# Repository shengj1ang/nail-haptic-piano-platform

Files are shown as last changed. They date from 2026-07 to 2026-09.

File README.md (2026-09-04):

# Nail-Mounted Haptic Cues for Piano Training and Tele-training

Code repository for the MSc project of the same name. It documents the
platform implementation, operation, validation tools, and analysis workflow.
The complete project report is included as
[`shengjiang_final_report.pdf`](shengjiang_final_report.pdf).

The platform is a multimodal piano-guidance rig: a MIDI keyboard with per-key
LED backlighting, ten nail-mounted vibrotactile actuators driven by a Teensy
4.1, an overhead camera for finger-use detection, and the experiment software
that runs and analyses the studies built on top of it.

Everything is reachable from one hub window:

```bash
cd main && python launcher.py
```

---

## Documentation index

**Every document lives in [`doc/`](doc/).** This README is the index and stays
short: each subject below is written up in exactly one place, and nothing here
repeats it.

### Start here

| Document | What it covers |
|---|---|
| **[doc/USER_MANUAL.md](doc/USER_MANUAL.md)** | **How to use the software.** A screenshot walkthrough of every launcher button, section by section: what each window is for, the steps you take in it, and what it writes. Start here if you want to *operate* the platform. |
| **[doc/PLATFORM.md](doc/PLATFORM.md)** | **How the software is built.** Directory layout, the calibration→detection pipeline, the study runner and the analysis windows, the data-maintenance tools, and the haptic configuration. Start here if you want to *change* it. |
| [doc/firmware.md](doc/firmware.md) | The Teensy 4.1 firmware: motors, LEDs, accelerometers, and the complete serial protocol. |
| [shengjiang_final_report.pdf](shengjiang_final_report.pdf) | The complete project report: research rationale, formal methods, results, discussion, and appendices. |

### The experiments

Four strands of experimental work, in the order they were built. Each has its
own protocol and write-up.

| Study | Launcher | Document |
|---|---|---|
| **Actuator validation** — resonance, intensity, motor→ACC delay, spectra, adhesives | Validation Experiments | [doc/validation-experiments.md](doc/validation-experiments.md), plus one document per experiment below |
| **Main User Study** — which cue modality teaches a key-and-finger mapping best | Main User Study, Data Analysis | method chapter of the report; stimulus algorithm in [doc/SEQUENCE_GENERATOR_ALGORITHM.md](doc/SEQUENCE_GENERATOR_ALGORITHM.md) |
| **Tele-training** — guidance delivered over a network | Tele-training | [doc/REMOTE_GUIDANCE.md](doc/REMOTE_GUIDANCE.md) |
| **Rhythm experiment** — what survives when the cue is withdrawn | Rhythm Experiment | [doc/RHYTHM_EXPERIMENT.md](doc/RHYTHM_EXPERIMENT.md) |

The validation experiments are experiments in the same sense as the others,
and they come first in the dependency order: they are why the cue amplitude
and frequency are the values they are rather than a guess.

| Validation experiment | Document |
|---|---|
| LRA resonance and intensity calibration (frequency + amplitude sweeps) | [doc/validation-lra-resonance.md](doc/validation-lra-resonance.md) |
| Actuator spectrogram (drive-frequency × amplitude intensity map) | [doc/validation-actuator-spectrogram.md](doc/validation-actuator-spectrogram.md) |
| Motor → accelerometer delay (LRA/ERM command-to-vibration latency) | [doc/validation-motor-acc-delay.md](doc/validation-motor-acc-delay.md) |
| Adhesion vibration comparison (three mounting adhesives, LRA) | [doc/validation-adhesion-comparison.md](doc/validation-adhesion-comparison.md) |

### Algorithms

| Document | What it covers |
|---|---|
| [doc/SEQUENCE_GENERATOR_ALGORITHM.md](doc/SEQUENCE_GENERATOR_ALGORITHM.md) | The Main User Study's stimulus generator: matched bimanual sequence families per difficulty level (α/β/γ), constraint-driven, seeded, with automatic difficulty validation. |
| [doc/melody-generator.md](doc/melody-generator.md) | The rhythm experiment's melody generator: motif-and-phrase construction, melodic rules in scale steps, static fingering, whole-beat rhythm, and the scoring that selects a candidate. |

### Deployment and reference

| Document | What it covers |
|---|---|
| [doc/server.md](doc/server.md) | The tele-training relay server as an operator guide: accounts and rooms, HTTP↔HTTPS, JWT keys vs TLS certificates, deploying `main/server/` on its own, and the full REST + WebSocket reference. |
| [doc/runtime-bin.md](doc/runtime-bin.md) | The drop-in folder for ffmpeg / 7z, which the data-maintenance tools search before `PATH`. |
| [doc/archived.md](doc/archived.md) | Superseded prototypes and two completed one-off studies, kept for provenance. |
| [doc/legacy-accelerometer-reader.md](doc/legacy-accelerometer-reader.md) | Legacy standalone LIS3DH reader, pre-dating the unified firmware. Reference only. |

---

## Repository structure

```
./
├── doc/                  every document in this repository, plus doc/image/
│                         for the screenshots the user manual uses
├── main/                 the Python platform - launcher hub, calibration wizards,
│   │                     quiz and study tools, analysis, all four studies
│   ├── app/                     UI package: camera + MIDI finger-detection pipeline, GUIs
│   ├── common/                  shared low-level serial / motor / LED modules
│   ├── remote_guidance/         tele-training clients
│   ├── server/                  the relay server - imports nothing from the platform
│   ├── melody_generator/        rhythm-experiment stimulus generator (stdlib only)
│   ├── rhythm_study/            rhythm-experiment sessions and analysis
│   ├── validation_experiments/  hardware validation experiments
│   ├── data/                    calibration profiles, stimuli, and every study's data
│   └── test-script/             the test suite, plus older non-UI hardware scripts
├── teensy_driver/        Teensy 4.1 firmware: motors (async PWM), WS2812 LEDs, LIS3DH
├── 3d_model/             SolidWorks models and STLs for the actuator mounts and case
└── archived/             superseded prototypes and completed one-off studies
```

---

## Getting started

**Platform support.** The platform is tested on **macOS** and **Windows**.
Both run the same code — the differences are confined to how the rig is named
(serial ports and MIDI ports enumerate differently) and to where the optional
ffmpeg / 7z binaries are found, and both are handled in the code rather than
left to the operator.

### Windows — the bundled package

Download the archive from
[Releases](https://github.com/shengj1ang/nail-haptic-piano-platform/releases),
unpack it anywhere, and **double-click `main\launcher.bat`**. The launcher
window comes up; there is nothing to install.

The bundle carries its own Python 3.11 interpreter under
`main\runtime\Python311\`, and `launcher.bat` puts that interpreter and
`main\runtime\bin\` on the PATH **for that window only** — nothing is
written to the system PATH or to the registry, and a Python you already have
installed is left alone.

### macOS, Linux, or Windows from source

Python 3.11+ and the pinned dependency set:

```bash
pip install -r main/requirements.txt
cd main && python launcher.py
```

That requirements file also carries the tele-training dependencies;
`main/server/requirements.txt` lists the relay's alone, for deploying that
folder by itself.

**Hardware.** A Teensy 4.1 running the `haptic-piano` firmware (verify with the
`E` command — see [doc/firmware.md](doc/firmware.md)), a MIDI keyboard, two
WS2812 LED strips, ten vibrotactile actuators, and a camera positioned above
the keyboard.

**First run.** Work through the launcher's Initial Setup section in order —
camera selection, keyboard calibration, MIDI mapping — before anything else.
Every later tool reads the calibration profile those wizards produce.
[doc/USER_MANUAL.md](doc/USER_MANUAL.md) walks through each window with a
screenshot; [doc/PLATFORM.md](doc/PLATFORM.md) explains what sits behind them.

---

## Notes for reviewers

- **This repository is the implementation record.** It documents what the
  software does, how it is built, and how to operate it. The
  [project report](shengjiang_final_report.pdf) provides the full research
  rationale and formal study methods.
  Where a design decision is constrained by the study methodology, the code
  comments identify the corresponding report section.
- **Each study's data stays in its own folder** under `main/data/`, and the
  studies are isolated from one another structurally rather than by
  convention — the constraints are stated in each study's document and are
  enforced by tests.
- **The test suite** is `main/test-script/`:

  ```bash
  cd main && QT_QPA_PLATFORM=offscreen python -m pytest test-script/ -q --ignore=test-script/test_led_array.py
  ```

  `test_led_array.py` is excluded because it prompts for a serial port on
  stdin; it is a hardware tool, not an automated test.
- **The manual's screenshots are regenerated, not re-photographed.**
  `main/test-script/capture_manual_screenshots.py` renders every window
  offscreen against a disposable copy of the project, with the camera, serial
  ports and MIDI stubbed, and writes `doc/image/`.

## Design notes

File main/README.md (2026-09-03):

# The platform

The Python side of the project: camera + MIDI finger-use detection, the
per-key LED backlight, the vibrotactile cue path, and the tools that run and
analyse every study built on them. The repository front door and its
documentation map are one level up, in [`../README.md`](../README.md).

Everything is reachable from one hub window, which groups the tools into the
numbered sections used throughout this file:

```bash
python launcher.py
```

Every tool also runs standalone from its own entry-point script.

## Where to read what

This file documents the platform and the tools that have no document of their
own. Anything with a dedicated write-up is **linked, not repeated** — if a
subject appears below in more than a paragraph or two, this is the only place
it is written up.

| Subject | Document |
|---|---|
| Repository front door, install, structure | [`../README.md`](../README.md) |
| Firmware and the serial protocol | [`../teensy_driver/README.md`](../teensy_driver/README.md) |
| **Main User Study** stimulus algorithm | [`SEQUENCE_GENERATOR_ALGORITHM.md`](SEQUENCE_GENERATOR_ALGORITHM.md) |
| **Tele-training** (section 8) | [`REMOTE_GUIDANCE.md`](REMOTE_GUIDANCE.md), and [`server/README.md`](server/README.md) for the relay |
| **Validation experiments** (section 10) | [`validation_experiments/README.md`](validation_experiments/README.md), plus one README per experiment |
| **Rhythm experiment** (section 11) | [`RHYTHM_EXPERIMENT.md`](RHYTHM_EXPERIMENT.md), and [`melody_generator/README.md`](melody_generator/README.md) for the generator |
| Study protocols and rationale | [`../shengjiang_final_report.pdf`](../shengjiang_final_report.pdf) |

What is written up **here** and nowhere else: the directory layout, the
FingerAccuracy pipeline and calibration profiles (sections 1–3), the Main
User Study runner and the analysis windows (sections 6–7), the quiz data
maintenance tools (section 9), the haptic actuator configuration, and the
LED/audio helper modules.

## Layout

```
app/                            UI package: camera + MIDI finger-accuracy detection, quiz, generator
launcher.py                     entry point - hub window for every tool below, grouped into the same
                                 numbered sections used throughout this README (1 Initial Setup ...
                                 12 Demo & About). Section 8 Tele-training is the one
                                 section whose buttons start SEPARATE processes rather than a
                                 sub-window, because a student, a teacher and a relay have to run at
                                 the same time - see "Tele-training" below.
                                 Section 9 Tools is data housekeeping, not part of running or
                                 analysing a session - see "Quiz data maintenance tools" below.
                                 Section 11 Rhythm Experiment is a separate study, deliberately
                                 isolated so it cannot affect any of the others - see "Rhythm
                                 experiment" below.
                                 Section 1 also holds two launcher-only settings windows: Visual
                                 Guidance Cue Selection (app/gui/cue_selection_window.py), which
                                 persists the quiz cue style (dot/hand) to config.json, and Haptic
                                 Actuator Defaults (app/gui/haptic_config_window.py), which persists
                                 the actuator in use and each actuator's default frequency/amp to
                                 config.json's "haptic" block (see "Haptic actuator configuration")

setup_camera_wizard.py          entry point - camera selection/orientation (section 1: initial setup)
setup_keyboard_wizard.py        entry point - app/ calibration wizard (section 1: initial setup)
setup_midi_mapping_wizard.py    entry point - app/ MIDI mapping wizard (section 1: initial setup)

test_keyboard_preview.py        entry point - app/ profile preview/sanity-check (section 2: feature testing)
test_finger_accuracy.py         entry point - live finger/key detector (section 2: feature testing, see app/)
test_virtual_piano_led.py       manual-test UI (PySide6): on-screen piano that lights the physical LED
                                 strips (section 2: feature testing)
test_haptic_vibrator.py         manual-test UI: per-finger vibration motor check (section 2: feature testing)
app/gui/accelerometer_window.py manual-test UI (launcher-only): live X/Y/Z plot of one LIS3DH from the
                                 rig's ACC stream, sensor id selectable + persisted to config.json
                                 (accelerometer.sensor_id) (section 2: feature testing)

experiment_sequence_wizard.py   entry point - generates the controlled bimanual stimulus sequences for
                                 the main user study (30-event, difficulty alpha/beta/gamma, seeded, with
                                 built-in difficulty validation) and saves them under data/sequence/ -
                                 see SEQUENCE_GENERATOR_ALGORITHM.md (section 3: experiment sequence design)

music_recording_wizard.py       entry point - records a song (video+MIDI) and saves a fingering-annotated
                                 score under data/music/<song>/ (section 4: recording & playback)
music_playback.py               manual-test UI (PySide6): replays a saved song on an on-screen 88-key
                                 piano + finger dots (section 4: recording & playback, see app/music_recording.py)

student_quiz.py                 entry point - cue-response quiz with VISUAL finger cue (section 5: practice & assessment)
student_quiz_haptic.py          entry point - same quiz with HAPTIC finger cue (section 5: practice & assessment)

student_remote_guidance.py      entry point - Student Client: receives a remote teacher's key/finger
                                 guidance and cues it locally (section 8: tele-training)
teacher_remote_guidance.py      entry point - Teacher Client: turns what the teacher plays into
                                 guidance, and uploads/triggers pre-recorded sequences (section 8)
remote_latency_benchmark.py     entry point - relayed-path latency benchmark, CLI or --gui (section 8)
remote_guidance/                the tele-training client package (config, protocol, timing, network
                                 client, composite cue, student/teacher apps, benchmark) - see
                                 "Tele-training" below
server/                         the relay server: FastAPI REST + WebSocket, SQLite, JWT auth. Copyable
                                 on its own to a remote host; imports nothing from this platform.
                                 Full operator documentation in server/README.md
REMOTE_GUIDANCE.md              design + handover notes for the whole tele-training module: file map,
                                 the invariants that must not be broken (reaction-time origin, clock
                                 rules, what the server may not do), traps, and the list of known gaps.
                                 START HERE before changing anything under remote_guidance/ or server/
RHYTHM_EXPERIMENT.md            the rhythm experiment written up as Introduction / Method / Results /
                                 Discussion: the melody generation algorithm, the 19-trial
                                 cue-withdrawal design, the measures and the analysis plan.
                                 START HERE before changing anything under rhythm_study/
quiz_analysis.py                entry point - batch offline analysis of saved quiz sessions: outcome
                                 metrics table, LED sync alignment, per-event review/correction,
                                 carry-over review, participant CSV export (section 7: data analysis)
tool_compress_review_videos.py  entry point (console) - scans data/quiz/*/review.mp4 and converts only
                                 non-H.264 review copies with ffmpeg; never enters raw/. A thin
                                 frontend over app/review_compress.py, which the launcher's
                                 "Review Video Compression" window (section 9) also drives
tool_backup_quiz_to_zip.py      entry point (console) - participant backup: creates one tested
                                 data/quiz-zip/Pxx.zip for each complete P01-P20 participant.
                                 A thin frontend over app/quiz_backup.py, which the launcher's
                                 "Participant ZIP Backup" window (section 9) also drives

config.json                     app/ settings (auto-created): camera/MIDI, active_keyboard_profile,
                                 visual_cue_style, haptic (actuator in use + per-actuator default
                                 frequency/amp - see "Haptic actuator configuration"), and
                                 remote_guidance (the tele-training block: relay URL plus the
                                 student's and teacher's own camera/MIDI/profile/serial ports - it
                                 never redefines the shared camera/midi/active_keyboard_profile
                                 above; see "Tele-training")
data/keyboard-profile/<profile>/   app/ calibration profiles (see "app/" below)
data/music/<song>/               saved teacher recordings (see app/music_recording.py)
data/sequence/<name>/            generated stimulus sequences (same meta.json/fingering.json layout as
                                 data/music/, see app/sequence_generator.py)
data/sequence_validation/<batch>/   difficulty-validation output for a generated sequence batch
                                 (app/stimulus_validation.py, viewable in the Sequence/Music Metrics window)
data/quiz/<attempt>/             saved quiz sessions (video+MIDI raw + analysis results; results.json
                                 carries per-event validity - "valid"/"invalid_carryover" - set during
                                 the manual carry-over review; raw/ also holds sync_align.json - the
                                 trial's confirmed LED sync anchor - and sync_detect.json, the audit
                                 trail of the anchor last used)
data/quiz-zip/Pxx.zip            optional participant-level backups created by
                                 tool_backup_quiz_to_zip.py; never used as live experiment input
data/validation_experiments/<experiment>/   timestamped CSV/PNG/raw_acc.npz/meta.json runs of the
                                 validation experiments (see validation_experiments/ below); the
                                 raw_acc.npz holds the run's full three-axis accelerometer samples,
                                 so both intensity metrics and every chart can be regenerated
                                 offline
data/remote_guidance/latency/<run>/   latency benchmark output: samples.csv, summary.json,
                                 latency.png (see "Tele-training")
data/MainUserStudy/<participant>/   TrialStructure.json - the participant's randomised 27-trial
                                 schedule + live progress (see app/pilot_study.py); the Formal
                                 Experiment Session (launcher section 6, no standalone script)
                                 updates and resumes from this file after a crash. Also the export
                                 target: <P>_trials.csv / <P>_events.csv and figures/ (300 dpi
                                 PNGs + per-analysis CSVs from Participant Analysis)
hand_landmarker.task            MediaPipe hand landmark model, used by app/
requirements.txt                Python deps for app/ (conda env "fingercam")

profile_led_mapper.py           reusable, GUI-free: profile + MIDI note -> LED positions
note_led_map.py                 this LED rig's fixed wiring (position -> LED pixels), used by profile_led_mapper.py
note_audio.py                   reusable, GUI-free: MIDI note -> audio tone playback (no profile needed)

common/                         shared low-level modules (serial/motor/LED), used by both
                                 test_virtual_piano_led.py and test-script/
validation_experiments/         small hardware-validation experiments, separate from the main study
                                 (section 10: validation experiments) - one subfolder per experiment
                                 plus three shared modules: rig.py (serial helpers + the ACC sample
                                 collector), acceleration_metrics.py (the two vibration-intensity
                                 metrics, the counts -> m/s^2 conversion and the raw three-axis
                                 sample store) and report.py (the console-style text statistics each
                                 experiment can rebuild from a saved run, printed by the GUI when a
                                 run is loaded). GUI wrappers in
                                 app/gui/validation_experiment_window.py. Currently:
                                 lra_resonance_intensity_calibration/ (frequency + amplitude sweeps),
                                 actuator_spectrogram/ (2-D drive-frequency x amp intensity map),
                                 motor_acc_delay_experiment/ (LRA/ERM command-to-vibration latency)
                                 and adhesion_vibration_comparison/ (relative vibration transfer of
                                 three mounting adhesives, LRA-only, with its own three-run
                                 comparison analysis),
                                 each with a full write-up in its README.md; validation_experiments/
                                 README.md documents the shared metric/raw-data layer. Runs are saved
                                 as timestamped CSV/PNG/raw_acc.npz/meta.json sets under
                                 data/validation_experiments/<experiment>/
melody_generator/               SEPARATE STUDY (launcher section 11): standalone generator of short,
                                 simple, fixed-fingering practice melodies for the rhythm experiment.
                                 Stdlib only, shares no code with app/sequence_generator.py, writes
                                 only data/rhythm_experiment/ - see RHYTHM_EXPERIMENT.md
rhythm_study/                   SEPARATE STUDY (launcher section 11): the run-time and analysis half -
                                 the 19-trial schedule, the session controller and trial runner, and
                                 the whole analysis stage. Writes data/RhythmStudy/ and the
                                 rhythm- prefixed folders under data/quiz/ - see RHYTHM_EXPERIMENT.md
test-script/                    older, non-UI motor/LED/latency/MIDI scripts + their output
read_data_from_accelerometer/   legacy standalone LIS3DH sketch + plotters (old bare "x,y,z" serial
                                 format, pre-unified-firmware) - reference only, see its README;
                                 the live tool for the current rig is Accelerometer Live View above
../archived/python-prototypes/  the former archive/ folder: early FingerAccuracy prototypes,
                                 one-off utilities, and old bug reports - reference only
runtime                         Python Environment in Windows, python 3.11.9, do not use or read or change this diretory when in development
runtime/bin/                    optional drop-in folder for ffmpeg / 7z executables (see
                                 "Where ffmpeg and 7z come from" below). Searched before PATH;
                                 the executables themselves are not committed
venv.bat                        Do not read/write this file
launcher.bat                    Do not read/write this file
```

---

## Quiz data maintenance tools (launcher section 9)

Two tools for looking after data that has already been collected. Neither
is part of running a session or analysing one, and neither reads anything
the experiment reads.

Each has two frontends over one implementation:

| | window (launcher section 9) | console | shared logic |
| --- | --- | --- | --- |
| review videos -> H.264 | Review Video Compression | `python3 tool_compress_review_videos.py` | `app/review_compress.py` |
| participant backups | Participant ZIP Backup | `python3 tool_backup_quiz_to_zip.py` | `app/quiz_backup.py` |

The window and the script do the same thing to the same files, because
neither decides anything: **Scan** is the script's first phase, and
**Convert** / **Create archives** is what answering `1` at its prompt
does. Everything below describes both. The windows add only what a
terminal cannot: a table of what was found, an overall and a per-file
progress bar, a running log, and a **Stop** button.

Paths are anchored to this `main/` directory, so the scripts no longer
have to be run from here (though they still can be), and the windows work
wherever the launcher was started from.

Both windows keep running when you open another launcher tool - a
conversion pass is minutes of work and should not be thrown away by a
button press - and both are closed by closing the launcher.

### Where ffmpeg and 7z come from

Neither program is a Python dependency, so `app/tool_binaries.py` looks
for them in two places, in this order:

1. **`main/runtime/bin/`** - drop `ffmpeg.exe` / `7z.exe` (or their
   macOS/Linux equivalents) in that folder and nothing has to be
   installed on the machine. `launcher.bat` prepends the folder to `PATH`
   for the window it starts, and `app/tool_binaries.py` prepends it
   in-process as well, so anything the tools start themselves finds the
   same copy. Both are temporary: nothing is written to the system `PATH`
   or the registry.
2. **`PATH`**, as installed system-wide.

The lookup uses `shutil.which`, so on Windows the name `7z` finds
`7z.exe` without the extension being spelled out. 7-Zip is accepted under
any of the names `7z`, `7zz` or `7za` - all three can write and test the
ZIP archives the backup tool asks for.

Each window shows which copy it is using, or a warning naming
`runtime/bin` if it found none, and has a **Re-check** button so a
program dropped in there is picked up without restarting the launcher.
The console tools print the same message and exit with status 2 rather
than starting work they cannot finish.

### Compress generated review videos to H.264

```bash
python3 tool_compress_review_videos.py
```

Scans every direct `data/quiz/<attempt>/review.mp4`, reports its codec,
and asks before making changes. Files already encoded as H.264 and
unreadable or unknown files are skipped. The path pattern cannot enter
`data/quiz/<attempt>/raw/`, so original `raw/performance.mp4` recordings
are outside the tool's scope.

For each non-H.264 review, the tool renames the source to
`tmp-review.mp4` and runs this exact conversion command in that attempt
directory:

```bash
ffmpeg -i tmp-review.mp4 review.mp4
```

No options are added to it - the MP4 defaults, including H.264 video, are
the point. (The window's per-file progress bar reads the frame counter
from the stderr ffmpeg writes anyway, so watching a conversion needs no
extra flag either.)

The temporary original is deleted only after the output is non-empty,
confirmed as H.264, fully decodable by ffmpeg, and has exactly the same
frame count as the source. If ffmpeg is absent, disappears, fails,
produces an empty file, produces a non-H.264 file, or changes the frame
count, the source is not deleted. The tool restores the original
`review.mp4` and preserves any failed output as `failed-review.mp4` (or
the next unused numbered name). An existing `tmp-review.mp4`, output
file, or symbolic link is never overwritten.

Pressing **Stop** (or Ctrl-C) mid-conversion is handled as one more way
for that file to fail: ffmpeg is terminated, the original is put back,
and the discarded output is left as `failed-review.mp4` for you to look
at and delete. Files not reached yet are simply not touched.

Because a conversion is only safe if the result can be proved equivalent,
each file costs three ffmpeg passes - decode the original, encode, decode
the result - which is why the window has a per-file bar as well as an
overall one, and why a full pass over a study's worth of reviews is an
hour-scale job.

### Back up complete participants as ZIP files

```bash
python3 tool_backup_quiz_to_zip.py
```

Previews every archive it is ready to create and asks for confirmation
before creating `data/quiz-zip/`. Only participant directories matching
P01 through P20 and trial T01 through T27 are eligible. A participant is
archived only after all 27 trial numbers are present, preventing an
incomplete `Pxx.zip` from being permanently skipped as an existing backup
on a later run. `TEST-*`, `remote-*`, other unexpected directory names,
symbolic links used in place of trial directories, and `.DS_Store` files
at every depth are excluded.

Each participant is written first as `data/quiz-zip/tmp-Pxx.zip` with
`7z a -tzip`, so the archive format is ZIP rather than 7z. The temporary
archive must pass `7z t` before it is renamed to `Pxx.zip`. Existing
`Pxx.zip` and temporary archives are never overwritten. A failed,
stopped or interrupted temporary archive is preserved for inspection -
and must be removed by hand before that participant can be retried - and
no source directory or source file is ever deleted or modified.

This tool used to refuse to run anywhere but macOS. It no longer does:
the work is one 7z invocation over relative paths, which is as true on
Windows as it is on macOS, and which 7z to use now comes from the lookup
described above rather than from an assumed Homebrew install.

The window's table is the preview, one row per participant, and its
State column is the reason that participant is or is not being archived
("ready", "incomplete" with the missing trials named, "archive exists",
"temporary archive exists") - which between sessions is usually the
question being asked.

### Tests

```bash
python3 test-script/test_maintenance_tools.py
```

Runs against a temporary `data/quiz` built for each test; the project's
own data is never read or written. The conversion and archiving tests
skip themselves if ffmpeg or 7z is not available.

---

## Rhythm experiment (launcher section 11)

A study of its own, separate from the Main User Study. That one asks which
cue modality teaches best; this one asks what survives when a cue is taken
away. One 15-note melody, played 19 times, with guidance withdrawn on a
schedule:

    Training x5 -> Probe 1 -> Training x5 -> Probe 2 -> Training x5 -> Probe 3 -> Final test

| phase | backlight | haptic | task | n |
|---|---|---|---|---|
| Training | on | on | cue/response | 15 |
| Probe | on | off | performance | 3 |
| Final test | off | off | performance | 1 |

Five buttons, in the order a session uses them: **Rhythm Melody Generator
(15-note)** and **Playback Rhythm Melody** make and audition the stimulus;
**Rhythm Trial Schedule** locks a participant to one melody and writes their
19-trial schedule; **Rhythm Experiment Session** runs it (two windows - the
session controller and the trial runner - and no participant-facing cue
screen, because this study has no visual guidance); **Rhythm Group Analysis**
is the whole analysis stage.

**It cannot disturb any earlier experiment.** That is structural, not a
convention: `melody_generator/` shares no code with `app/sequence_generator.py`
and has no third-party dependencies, `rhythm_study/` never imports
`app/pilot_study.py` or `app/sequence_generator.py` (a test parses the imports
to enforce it), nothing here writes `config.json`, a keyboard profile,
`data/sequence/`, `data/music/` or `data/MainUserStudy/`, and its melodies are
not registered with `app/song_library.py` so one can never appear in the song
pickers. The two studies meet only in the shared `data/quiz/` folder, where
the `rhythm-` prefix separates them.

### Where the rhythm-experiment documentation is

This section is orientation only. Nothing below is repeated here:

| Document | What it covers |
|---|---|
| **[RHYTHM_EXPERIMENT.md](RHYTHM_EXPERIMENT.md)** | The study, written up as Introduction / Method / Results / Discussion: the research question, where it sits among the platform's four experiments, the melody generation algorithm, the 19-trial design, why training and the probes are different *tasks* and what that means for the timing measures, every derived measure, and the analysis plan. |
| [melody_generator/README.md](melody_generator/README.md) | The generator as a tool: CLI, config, the four generation ideas in detail, the hand layouts, the full validation-code list, the scoring, the output file formats, and using it as a library. |

## app/ - FingerAccuracy pipeline

Camera + MIDI based detection of *which finger* pressed *which piano key*.

### Where this fits

This is the "which finger pressed this key" piece of a bigger piano
practice / learning experiment setup. Roughly, the full pipeline looks
like:

```
cue shown -> participant presses a key
  -> MIDI logs the key + a timestamp -> camera works out which finger -> analysis after the fact
```

`app/` only covers the camera part, but it's built so it can be called from
the rest of that pipeline either live during a session, or later from a
recording - see [Using it as a library](#using-it-as-a-library).

### How it works

There are three steps, and only the first two need doing once per
physical setup:

1. Calibrate: click on the camera image to mark each key's exact pixel
   range (a paint-bucket style fill, bounded by Canny edges). This gets
   saved as a *profile* - `data/keyboard-profile/<profile_name>/keyboard_template.json` plus
   `keyboard_key_map.png`, a pixel map where each pixel's value is the key
   id it belongs to plus one (0 for background).
2. Map MIDI notes to those keys: press the keys in order 1, 2, 3, ... and
   whatever MIDI note number each one actually sends gets recorded next to
   the template, as `midi_mapping.json`.
3. Live detection: MediaPipe finds fingertip pixel positions every frame.
   On each MIDI note-on, look up which key that note belongs to, then
   check which fingertip's pixel is inside that key's region (or closest
   to it, if none are) - that's the finger used.

Left hand thumb -> pinky = `L1`..`L5`, right hand thumb -> pinky =
`R1`..`R5`. Works fine with 0, 1, or 2 hands in frame - both hands showing
up isn't required.

A profile only stays valid as long as the camera and keyboard don't move
relative to each other. If they do, just re-run step 1.

### Setup

```bash
conda activate fingercam    # or: conda env create ...; pip install -r requirements.txt
```

Everything runs inside the `fingercam` conda environment (Python, OpenCV,
MediaPipe, mido, PySide6). `hand_landmarker.task` (MediaPipe's model file)
is bundled in this folder already.

### Pipeline scripts

Run these from inside `main/`.

| Script | Purpose |
|---|---|
| `setup_keyboard_wizard.py` | PyQt wizard - calibrate a new profile (click-based, no keyboard shortcuts). |
| `setup_midi_mapping_wizard.py` | PyQt wizard - press keys 1..N in order, records the MIDI note each sends. |
| `test_keyboard_preview.py` | Utility/demo - pick a profile from a dropdown and sanity-check it against the live camera, optionally showing MIDI note names instead of key numbers. |
| `test_finger_accuracy.py` | The live app - keyboard overlay + hand skeleton + real-time finger/key matching. |
| `test_virtual_piano_led.py` | Manual-test UI - on-screen piano that lights the physical LED strips (see below). |
| `music_recording_wizard.py` | PyQt wizard - records a song (video+MIDI), flashes the LEDs for sync, and saves a fingering-annotated score under `data/music/<song>/`. |
| `music_playback.py` | Manual-test UI - replays a saved song on an on-screen 88-key piano, lighting a dot for whichever finger played each note. |
| `experiment_sequence_wizard.py` | Stimulus generator for the main user study - matched families of 30-event bimanual sequences per difficulty level (α/β/γ), constraint-driven (D = C_m/C_s/C_c), seeded for reproducibility, with automatic difficulty validation. Algorithm: `SEQUENCE_GENERATOR_ALGORITHM.md`. Includes the read-only "Sequence/Music Metrics" viewer (`app/gui/sequence_metrics_window.py`). |
| `student_quiz.py` / `student_quiz_haptic.py` | Cue-response quiz over a saved song/sequence: LED key cue plus a visual (`student_quiz`) or nail-mounted haptic (`student_quiz_haptic`) finger cue; records the whole session (video+MIDI) under `data/quiz/<attempt>/` for offline scoring. **Preview keyboard profile** draws the active calibration profile over the live camera image before recording - see [Checking the camera against the profile](#checking-the-camera-against-the-profile). |
| `quiz_analysis.py` | Batch offline analysis of saved quiz sessions: a checkable multi-quiz table with the report's full per-trial outcome measures, LED-anchored video/MIDI sync alignment (auto + manual), per-trial detail / per-event review-and-correction windows (including the carry-over validity review), and one-click per-participant CSV export - see [Data analysis](#data-analysis-launcher-section-7). |
| launcher section 6 (no standalone scripts) | The main user study tools: **Participant Trial Schedule** (`app/gui/pilot_schedule_window.py`) builds and saves a participant's randomised 27-trial schedule; **Formal Experiment Session** (`app/gui/experiment_session_window.py`) runs it - see [Main user study](#main-user-study-launcher-section-6). |
| launcher section 7, Participant Analysis (no standalone script) | Cross-trial single-participant analysis (`app/gui/participant_analysis_window.py`): condition/difficulty/learning charts, speed-accuracy trade-off, event-level error breakdown, finger confusion matrices, per-finger profiles - with 300 dpi figure + tidy CSV export. |
| `test_haptic_vibrator.py` | Manual test - drive each finger's vibration motor individually. |
| `setup_camera_wizard.py` | Camera selection/orientation wizard. |
| `launcher.py` | Hub window - one button per script above, grouped by stage; only one tool is open at a time (they share the camera). |

```bash
python setup_keyboard_wizard.py
python setup_midi_mapping_wizard.py
python test_finger_accuracy.py
python music_recording_wizard.py
python music_playback.py
```

Each script's docstring has more detail; `config.json` (auto-created on
first run) holds the camera index/flip settings, Canny thresholds, the
MIDI port, and which profile is "active" (used by default when a script
doesn't ask you to pick one).

**These wizards configure the machine the experiment runs on.** They
write the top-level `camera`, `midi.port_name` and
`active_keyboard_profile`, and the calibration wizard saves over
`data/keyboard-profile/<name>/`. That is what they are for - and it means
they are the wrong tool for onboarding a tele-training partner, because
each of those keys is what the quiz and the Formal Experiment Session
read, and a recorded session's scoring is only reproducible while its
profile folder stays as it was. For a remote student or teacher, use
**Tele-training Setup Wizard** (section 8) instead: the same calibration
work, saved into its own new profile folder and touching no config key.

### Checking the camera against the profile

The finger judgement is only ever as good as the camera still seeing the
keyboard the way it was calibrated - nudge the tripod and every key id
shifts, silently, and the first sign of it is a trial's finger accuracy.

**Preview keyboard profile** answers that in one click. It draws the
active profile's colored key masks and key ids over the camera image and
opens the result in its own window; nothing is saved. It is on:

- **Quiz - Visual Guidance** and **Quiz - Haptic Guidance** (section 5),
- the main study's **Trial runner** (section 6), which inherits it,
- both remote clients' Settings dialogs (section 8), where it opens the
  camera for one snapshot because those windows hold no camera yet.

In the three quiz windows it annotates the frame already on screen rather
than opening a second capture, since those windows hold the camera for
their whole lifetime. It uses `active_keyboard_profile` - the same
profile that trial is about to be scored with, not a separate choice -
and it is disabled while a quiz is recording. If the camera resolution
and the profile's mask disagree, it says so instead of stretching the
mask, because a stretched mask makes a wrong calibration look aligned.

The shared implementation is `app/gui/profile_preview.py`.

**Two keyboards of the same model report the same MIDI port name.** Every
port picker here lists them as `SE25 MIDI1 #1` and `SE25 MIDI1 #2`,
numbered in the order this machine enumerates them; a name that is
reported only once keeps exactly the name the driver gives it, so a
single-keyboard setup and any older `config.json` are unaffected. The
numbering is not a device identity - it can change when something is
replugged. `python test-script/MIDI.py` listens on every port at once and
prints which label a key press arrived on, which is the quickest way to
tell two identical instruments apart; `python test-script/midi_probe.py
"SE25 MIDI1 #2"` does the same for one port. On macOS, renaming the
instruments in Audio MIDI Setup → MIDI Studio makes the raw names differ
and the suffixes disappear.

### Main user study (launcher section 6)

The formal experiment tools have no standalone entry scripts - open them
from `launcher.py`, section "6. Main User Study":

1. **Participant Trial Schedule** (`app/gui/pilot_schedule_window.py`) -
   enter the participant's metadata, lock them to one generated stimulus
   batch under `data/sequence/`, and generate + save the randomised
   27-trial schedule (3 conditions x 3 levels x 3 unique sequences per
   cell, seeded shuffle, 2-min rests after trials 9 and 18) to
   `data/MainUserStudy/<participant>/TrialStructure.json`.

2. **Formal Experiment Session** (`app/gui/experiment_session_window.py`) -
   opens three windows at once:

   - **Session controller** - load a saved participant and see every
     trial's live status. Each row has a tick box plus its own Start
     button; shortcut buttons select the remaining trials of one
     condition ("Select remaining Visual (B)" etc.). "Run selected trials
     in order" walks the ticked trials smallest-index-first, pausing for
     a manual Continue between trials (with the 2-min rest countdown
     after trials 9/18). Every status change is written straight back to
     `TrialStructure.json`, so a crashed session reloads with its exact
     progress and resumes from the first non-completed trial.
   - **Trial runner** (`app/gui/experiment_runner_window.py`) - the quiz
     window re-purposed for scheduled trials: connect the LED strip and
     pick the MIDI port/timbre/timeout here once, and use **Preview
     keyboard profile** to confirm the camera still matches the
     calibration before the first trial. Every trial records an
     ordinary quiz under `data/quiz/`, named
     `<participant>-T<index>-<condition><level>` (a rerun appends `-r2`,
     `-r3`, ... so no attempt's data is overwritten), which means the
     existing analysis tools (Quiz Analysis, review video) work on pilot
     trials unchanged. The per-trial analysis popup is suppressed
     mid-session; batch the analysis afterwards from launcher section 7.
   - **Participant-facing cue screen** (`app/gui/experiment_cue.py`) -
     created once per session, so it can be dragged/fullscreened onto the
     external display one time instead of reopening every trial.
     Condition B draws the visual finger cue on it; conditions A and C
     show only a status line, so no visual finger cue leaks into them.

   The three feedback conditions (`app/pilot_study.py`): **A** key-light
   only, **B** visual finger cue (dot/hand style from `config.json`'s
   `visual_cue_style`), **C** vibrotactile finger cue (per-finger motors,
   `app/haptic_cue.py`, rig connected lazily on the first C trial).

   Trials always run with `config.json`'s `active_keyboard_profile` (MIDI
   mapping + LED layout, same as every quiz); the `keyboard_profile`
   stored inside `TrialStructure.json` is *not* used at run time - it only
   records which profile limited the sequence generator's key range when
   the schedule was made.

### Data analysis (launcher section 7)

Every stored time in the codebase is an absolute Unix epoch timestamp
(`time.time()` floats - no ISO strings, no recorder-relative clocks;
`../archived/python-prototypes/migrate_to_epoch_timestamps.py` converted the pre-existing
data). The analysis workflow, all reachable from launcher section
"7. Data Analysis":

1. **Quiz Analysis** (`quiz_analysis.py` /
   `app/gui/quiz_analysis_window.py`) - the per-trial hub. Every saved
   quiz is a row in a checkable table (filter box + select
   shown/analyzed/not-analyzed shortcuts) with the report's full outcome
   measures as columns: Key Accuracy, the three finger-accuracy views
   (FA main = key∧finger over all events - the primary measure; FA |
   key ok; Note Accuracy | finger ok), stratified reaction times,
   timeouts/wrong-key counts, the carry-over review state, QC extra-press
   counts, unresolved/ambiguous detection rates, same-hand vs hand-switch
   splits, per-finger FA/TE (L1-L5, R1-R5), and FA under alternative
   thresholds θ ∈ {0.30..0.50}.

   - **Video sync**: mapping MIDI timestamps to video frames goes
     through `app/sync_led.py` - the trial's LED flash is auto-detected
     in the footage (box matched filter with the commanded pulse width +
     two self-checks) and saved to `raw/sync_align.json`; the per-row
     "Video Sync" button opens a 3-frame manual alignment window
     (`app/gui/video_sync_window.py`) for trials the detector can't
     handle. A saved (especially manual) alignment always wins over
     re-detection. Per-trial camera start-up error is real: −0.2 s to
     +0.55 s measured across the pilot data.
   - **Analyze selected (from video)** runs the MediaPipe pipeline +
     review-video render per checked quiz - behind a confirmation
     dialog, because it overwrites the detected-finger fields in
     `results.json` (manual finger corrections are lost; carry-over
     validity verdicts are kept). **Auto-align selected** (also behind a
     confirmation) persists fresh LED-flash detections as `sync_align.json`,
     skipping anything already aligned.
   - **Double-click a quiz** for the per-trial detail window
     (`app/gui/quiz_detail_window.py`): all 30 events with verdicts,
     borderline-probability highlighting, a finger confusion matrix and
     distribution stats. **Double-click an event** there to play back
     its keypress ±5 s and correct the detected finger
     (`app/gui/event_review_window.py`) - corrections change
     `actual_finger` only (softmax kept as the audit trail) and are
     flagged in a Manual column. Saving rewrites `results.json` and
     re-derives the headline numbers cached in `meta.json` in the same
     step (`app.quiz.save_quiz_summary`), so an edited quiz is never left
     quoting pre-correction figures and there is no follow-up pass to
     remember. Nothing reads that cache anyway - the table, the export
     and Group Analysis all recompute from the per-event data - it exists
     so a quiz folder is readable on its own.
   - **Carry-over review**: a matched response faster than 100 ms
     (`CARRYOVER_RT_THRESHOLD_S`) cannot be a reaction to its cue - pilot
     data shows these are the tail of the previous event's presses
     crossing the 0.4 s inter-event gap. Such events are flagged
     "review!" in the detail window's Validity column (counted as
     `suspected_carryover`), never auto-labelled anticipation.
     **Right-click the event row** to confirm one as `invalid_carryover`
     (or restore it): confirmed events are excluded from every statistic
     - RT and accuracy alike - and reported as `excluded_carryover`.
     Unmatched raw presses (near-simultaneous double-hits + inter-trial
     strays) are QC/debug info only (`qc_*` export columns, the detail
     window's QC line); they never enter the main outcome measures.
   - **Export participant data** writes `<P>_trials.csv` /
     `<P>_events.csv` (no wall-clock timestamps - RTs, verdicts and
     validity only) next to the participant's `TrialStructure.json`.
     These files are snapshots and Group Analysis reads them rather than
     `results.json`, so this is the one step to re-run after a round of
     finger corrections or carry-over verdicts.

2. **Participant Analysis** (`app/gui/participant_analysis_window.py`) -
   cross-trial, within-subject: nine tabs (overview, learning
   progression incl. the within-cell trial 1→3 trend, difficulty,
   speed-accuracy trade-off, event-level error breakdown + wrong-key
   distance, per-condition finger confusion with a paper view, per-finger
   profiles + RT boxplots, RT distributions, data-quality audit), each
   with an auto-generated caption. Computations live GUI-free in
   `app/participant_analysis.py` (pandas DataFrames, participant-agnostic
   - ready for the future multi-participant aggregation) over the rows
   from `app/participant_export.py`, with unit tests in
   `test-script/test_participant_analysis.py`. "Export figures + data"
   writes 300 dpi PNGs + tidy CSVs (`<P>_<slug>.png/.csv`) under
   `data/MainUserStudy/<P>/figures/`.

   All participant-level readouts are descriptive; group-level inference
   is a separate, later step.

### Profile folder layout

```
data/keyboard-profile/<profile_name>/
  keyboard_template.json   # key ids, kind (white/black), note (usually null)
  keyboard_key_map.png     # pixel map: value = key_id + 1, 0 = background
  midi_mapping.json        # key_id -> MIDI note number (+ note name), from step 2
```

`data/` also holds the experiment data alongside these calibration
profiles, each kind in its own subfolder (`music/`, `sequence/`,
`sequence_validation/`, `quiz/`, `MainUserStudy/` - see the layout at the
top of this file).

Multiple profiles can coexist (different desks, cameras, keyboards); every
tool has a dropdown or `active_keyboard_profile` in `config.json` to pick
between them.

### Using it as a library

Nothing here is locked to the PyQt UI - the GUIs in `app/gui/`
are thin wrappers around plain functions/classes in the top-level package.

```python
from app import (
    Config, Camera, HandTracker, MidiListener,
    KeyboardTemplate, MidiMapping, match_note_to_finger,
)

cfg = Config.load()
template = KeyboardTemplate.load(f"data/keyboard-profile/{cfg.active_keyboard_profile}/keyboard_template.json")
mapping = MidiMapping.load(f"data/keyboard-profile/{cfg.active_keyboard_profile}/midi_mapping.json")

tracker = HandTracker()
midi = MidiListener()          # picks the first available port if none given;
                               # pass a name from list_input_ports() to choose one

with Camera(cfg.camera) as cam:
    while True:
        frame = cam.read()
        hands = tracker.process(frame)          # {"Left": Hand(...), "Right": Hand(...)}

        for event in midi.pop_events():         # MidiEvent(time, note)
            match = match_note_to_finger(event.note, template, mapping, hands)
            if match:
                print(match.finger, "pressed key", match.key_id + 1, "note", event.note)
```

#### Record now, analyze later

`MidiListener` timestamps every event with an absolute epoch `time.time()`
(the project-wide convention - see [Data analysis](#data-analysis-launcher-section-7)),
so a session's MIDI can be logged and matched against a recorded video
afterward instead of processed live:

```python
from app import MidiListener, save_midi_log, analyze_recording

midi = MidiListener()
# ... run your experiment, e.g. cv2.VideoWriter recording the same camera ...
save_midi_log(midi.pop_events(), "session1_notes.json")

# Later, with no camera or MIDI device needed:
results = analyze_recording(
    video_path="session1.mp4",
    midi_log_path="session1_notes.json",
    keyboard_profile_name="desk_webcam",
    sync_path="session1_sync.json",   # SyncInfo - see below
)
for r in results:
    print(r)   # FingerMatch(note=..., key_id=..., finger=..., inside=...) or None
```

Epoch event times are mapped to video frames through `sync_path` - a saved
`app.music_recording.SyncInfo` (video/MIDI start times plus the sync LED
flash times), which `app/sync_led.py` anchors on the flash it detects in
the footage; this is exactly how the recording/quiz tools save their
`raw/sync.json`. Without `sync_path`, event times are assumed to already
be video-relative seconds (the legacy pre-epoch convention only).

`Camera` also accepts a video file path in place of a live camera index
(`CameraConfig.index` takes either) - useful for replaying a recording
through the same live-style code path instead of `analyze_recording`.

### app/ module layout

```
app/
  camera.py                    # Camera - cv2.VideoCapture wrapper (index or video file)
  config.py                    # Config / *Config dataclasses, JSON load/save
  hand_tracking.py             # HandTracker, Hand - MediaPipe wrapper, L1-L5/R1-R5 fingertips
  midi.py                      # MidiListener, MidiEvent, save/load_midi_log, and the port
                               #   layer every tool enumerates/opens through:
                               #   list_input_ports / resolve_input_port / MidiInputReader
                               #   (rtmidi by index - mido cannot address two identical keyboards)
                               #   (all event times are absolute epoch timestamps)
  finger_matching.py           # match_note_to_finger, FingerMatch - the core matching logic
  offline.py                   # analyze_recording - recorded video + MIDI log -> matches,
                               #   frame mapping via the LED sync anchor (app/sync_led.py)
  sync_led.py                  # video/MIDI sync anchoring: LED flash detection, sync_align.json
                               #   persistence (manual > auto > start-times fallback)
  profiles.py                  # list_profiles - discover data/keyboard-profile/<name>/ folders
  music_recording.py           # song save/load (meta.json/fingering.json), raw capture, sync marks
  song_library.py              # combined data/music/ + data/sequence/ listing for song pickers
  sequence_generator.py        # stimulus generation: D = (C_m,C_s,C_c) metrics, level constraints,
                               #   matched families, seeded RNG (see SEQUENCE_GENERATOR_ALGORITHM.md)
  stimulus_validation.py       # difficulty validation of the alpha/beta/gamma level pools
  pilot_study.py               # main user study: 27-trial randomised schedules (3 conditions x
                               #   3 levels x 3 sequences, final report § "Design and Procedure"), saved to
                               #   data/MainUserStudy/<participant>/TrialStructure.json with
                               #   per-trial status for crash-resume
  quiz.py                      # cue-response quiz logic shared by the visual/haptic quiz tools
                               #   and the pilot study's trial runner; summarize() computes the
                               #   report's per-trial outcome measures (three FA views, RT
                               #   stratification, per-finger stats, threshold sensitivity) and
                               #   excludes human-confirmed invalid_carryover events, reporting
                               #   suspected/excluded carry-over counts; count_extra_presses()
                               #   is the QC-only unmatched-press breakdown (double-hits vs
                               #   inter-trial strays)
  participant_export.py        # one participant's trials/events as unified rows (the adapter the
                               #   analysis + CSV export share); disk-first quiz-dir resolution
                               #   (highest -rN retake wins)
  participant_analysis.py      # GUI-free cross-trial computations (pandas, participant-agnostic):
                               #   speed-accuracy trade-off, event outcome classification, finger
                               #   confusion, wrong-key distance - unit-tested in test-script/
  haptic_cue.py                # per-finger vibration cue driver used by the haptic quiz and the
                               #   pilot study's condition C trials
  tool_binaries.py             # finds ffmpeg / 7z: runtime/bin first, then PATH (see "Quiz data
                               #   maintenance tools"); imports nothing from the rest of app/
  review_compress.py           # GUI-free: scan + convert data/quiz/*/review.mp4 to H.264, with the
                               #   rollback rules that make deleting the original safe. Driven by
                               #   tool_compress_review_videos.py and the section 9 window
  quiz_backup.py               # GUI-free: eligibility + one tested data/quiz-zip/Pxx.zip per
                               #   complete participant. Driven by tool_backup_quiz_to_zip.py and
                               #   the section 9 window
  keyboard/
    template.py                # KeyBox, KeyboardTemplate - the pixel-exact key map
    wizard.py                  # KeyFillWizard - paint-bucket key segmentation
    midi_mapping.py            # MidiMapping - key_id <-> MIDI note
    visualize.py                # color/label helpers for drawing a key_map
    detector.py                 # Canny edge detection used by the calibration wizard
  gui/                          # PyQt windows/pages for the scripts above (incl. the sequence
                                #   generator window, metrics viewer, validation dialog, cue window,
                                #   profile_preview.py - the shared "camera vs calibration" check
                                #   used by both quizzes, the trial runner and the remote clients;
                                #   the pilot-study windows: participant schedule, formal-session
                                #   controller, trial runner, participant-facing experiment cue
                                #   screen; and the analysis windows: quiz_analysis_window,
                                #   quiz_detail_window, event_review_window, video_sync_window,
                                #   participant_analysis_window; and the section 9 maintenance
                                #   windows: maintenance_window.py - the shared shell (worker
                                #   thread, progress bars, log, tool status) - with
                                #   review_compress_window and quiz_backup_window over it)
```

`../archived/python-prototypes/` holds earlier, now-superseded prototypes of this same detector
(`detect_finger_with_MIDI_keyboard_v2/v3/v4.py` plus their pickled models),
kept only for reference.

---

## profile_led_mapper.py + note_led_map.py - MIDI note -> LED, and test_virtual_piano_led.py - manual test UI

This LED rig is hardware-specific and isn't meant to generalize to other
keyboards, but the identifier it's keyed by is: `note_led_map.py` only knows
about *this strip's fixed wiring* (which pixel(s) light up for the Nth
white/black key, left to right - see `test-script/test_led_array.py`), and
its `NoteLEDMapper.light_key(note)` / `clear_key(note)` take a MIDI note
number directly, no separate key_id.

`profile_led_mapper.py` is the reusable, GUI-free glue that combines that
wiring with a calibration profile's actual `key_id -> note` mapping (from
`data/keyboard-profile/<profile>/`, produced by `setup_keyboard_wizard.py` +
`setup_midi_mapping_wizard.py`) to build a ready-to-use `NoteLEDMapper` -
`build_mapper(led, profile_name)` is the one-shot entry point. Import this
directly in any script that needs "MIDI note -> light the right LED"
without pulling in a GUI.

`test_virtual_piano_led.py` is a thin PySide6 wrapper around the above,
for manual testing: pick a profile, and an on-screen piano mirroring that
profile's calibrated keys appears. Press and hold a virtual key (or the
matching real MIDI key) and the corresponding LED(s) on the physical
Teensy WS2812 strips light up; release to turn them off.

```bash
python test_virtual_piano_led.py
```

If the keyboard's transpose/octave setting changes, only the profile needs
re-calibrating (`setup_midi_mapping_wizard.py`) - `note_led_map.py`'s wiring table
doesn't need to change.

---

## note_audio.py - MIDI note -> audio tone playback

Reusable, GUI-free playback of a continuous tone for whichever MIDI note(s)
are currently held down, meant to be imported by future teaching modules
the same way `profile_led_mapper.py` is - a note-keyed `play_key(note)` /
`stop_key(note)` pair, mirroring `NoteLEDMapper`'s `light_key`/`clear_key`.
No calibration profile needed here: frequency comes straight from the MIDI
note number via the standard equal-tempered formula (note 69 = A4 = 440Hz),
since pitch is physics, not a fact about specific hardware.

```python
from note_audio import NoteAudioPlayer

with NoteAudioPlayer() as player:
    player.play_key(60)   # starts a middle-C tone, fades in
    ...
    player.stop_key(60)   # fades it back out
```

Uses `sounddevice` (already a project dependency via `test-script/measure_latency*.py`)
to mix all currently-held notes into one output stream, with a short linear
fade on press/release to avoid clicks.

---

## common/ - shared serial/motor/LED modules

Low-level modules shared by `test_virtual_piano_led.py` above and the scripts in
`test-script/` below. Not a UI on its own.

| Module | Purpose |
|---|---|
| `serial_utils.py` | Cross-platform auto-detection and opening of the serial port (USB/Arduino/Teensy first, with manual fallback). |
| `controller.py` | `VibratorController` - high-level async interface to the multi-motor vibration firmware (connect, pulse, stop). |
| `led_controller.py` | `LEDArrayController` - high-level interface to the Teensy WS2812 LED firmware (set pixel, clear, brightness). |
| `haptic_config.py` | The project's single source of truth for haptic actuator defaults: loads/validates/saves `config.json`'s `haptic` block, and hands every tool the actuator in use and its default frequency/amp (see "Haptic actuator configuration"). |

---

## test-script/ - older motor/LED/latency/MIDI scripts

Non-UI scripts from earlier stages of the project - motor control demos,
latency measurement, and MIDI/LED debugging tools. All import their shared
logic from `common/`.

| Script | Purpose |
|---|---|
| `demo_send_motor_command_async.py` | Demonstrates asynchronous motor control - starts one motor, injects others while it's still running, to show non-blocking behavior. |
| `demo_keyboard_control.py` | Real-time keyboard control - maps keys A-`;` to motors 0-9, supports multiple simultaneous key presses. |
| `detect_live_motor.py` | Real-time microphone-based detection tool for tuning vibration-detection parameters (threshold, frequency band). |
| `measure_latency.py` | Single-motor latency measurement - triggers a motor, detects the acoustic onset, estimates end-to-end latency. |
| `measure_latency_multi_motor.py` | Multi-motor latency measurement - random motor selection, multiple runs, per-motor comparison, automatic plotting into `latency_results/`. |
| `test_led_array.py` | Manual LED test script - lights specific pixels on specific strips to sanity-check wiring/colors. |
| `midi_probe.py` | Ground-truth calibration probe - prints the MIDI note number for each physical key as you press it, left to right. Takes an optional port name, so it can also check one specific instrument out of several. |
| `MIDI.py` | Minimal listener that prints every incoming note with the port label it arrived on, listening on **every** input at once - the quickest way to tell two identically named keyboards apart. |
| `plot_acc_from_ACC_stream_autostart.py` | Live-plots `ACC,x,y,z` accelerometer lines streamed over serial, sending the start/stop stream commands automatically. |
| `test_participant_analysis.py` | Unit tests for `app/participant_analysis.py` (the GUI-free cross-trial computation layer). |
| `test_acceleration_metrics.py` | Unit tests for `validation_experiments/acceleration_metrics.py` (both vibration-intensity metrics, unit conversion, the raw-sample round trip) and for the metric switching / old-CSV compatibility of the accelerometer experiments. |
| `test_haptic_config.py` | Unit tests for `common/haptic_config.py` and everything that reads it: old/partial `config.json` compatibility, range validation, atomic non-destructive saving, the Initial Setup window, the validation windows' defaults and prose, "manual value wins over the config", historical-run rendering, and the haptic quiz cue. |
| `test_validation_reports.py` | Unit tests for the validation experiments' text statistics (`validation_experiments/report.py` + each experiment's `summary_report()`) and for the saved-run picker in the validation windows. |
| `test_remote_setup_wizard.py` | Unit tests for the Tele-training Setup Wizard: opening it performs no camera scan/open; scan results require an explicit selection; calibration has Initial Setup's five pages and crop/full-frame coordinate handling; MIDI mapping loads the Middle C reference image and displays the live camera with next/mapped/unmapped key overlays; and neither flow can write config or a non-Tele-training profile. Cameras/MIDI are faked. |
| `test_chord_cue.py` | Unit tests for cueing a chord (remote guidance only): the haptic bitmask, the dot view's multi-highlight, the hand view's photo cycling, the LED's single flush, and the two guarantees that scope it - scoring stays single-note, and the single-finger path the local quiz and the main user study use is untouched. |
| `test_profile_preview.py` | Unit tests for `app/gui/profile_preview.py` and the **Preview keyboard profile** button the quiz windows inherit: the mask is drawn without touching the caller's frame, a resolution mismatch is refused rather than resized, the frame already on screen is used instead of a second capture, and every failure is reported rather than raised. No camera or profile on disk is needed. |
| `test_midi_ports.py` | Unit tests for `app/midi.py`'s port identity: two identically named keyboards both stay visible and are opened by index, older bare port names still resolve, and `MidiListener`/`RawMidiRecorder` end up on the port that was asked for. rtmidi is faked, so no keyboard is needed. |
| `test_quiz_summary_cache.py` | Unit tests for the `meta.json` summary cache (`app.quiz.apply_summary` / `save_quiz_summary`): a corrected finger and a confirmed carry-over both leave the cached headline numbers equal to what the analysis table and the participant export recompute live, `results.json` is never touched, and the identity fields (`guidance_type`, `note_count`, `analyzed`) survive a re-cache. Quiz folders are temporary; no video, MIDI or MediaPipe pass is involved. |
| `test_music_recording.py` | Unit tests for the saved-song lead-in - the gap between "the recording started" and "the playing started", which is the one place an absolute `time.time()` stamp and an elapsed duration can be mixed up silently - and for the two Song Recording Wizards writing a `meta.json` whose `duration_s` is the length of the piece rather than of the capture. Songs go to a temporary directory; no camera, MIDI device or MediaPipe pass is involved. |

`latency_results/` holds the plots/summary generated by the latency scripts;
`video_demo/` holds recorded demo videos of the latency tests.

Three things to know before trusting a latency number from these: motor pins
0 and 1 can conflict with serial on some boards, the supply has to be able to
drive every motor under test at once, and microphone placement dominates the
measurement. They estimate the *acoustic* end-to-end path - serial, MCU,
motor spin-up, sound propagation and audio capture together. The
instrumented, repeatable version of this measurement is the motor→ACC delay
experiment in launcher section 10, which uses an accelerometer instead of a
microphone: see
[validation_experiments/motor_acc_delay_experiment/README.md](validation_experiments/motor_acc_delay_experiment/README.md).

## Tele-training (launcher section 8)

Guidance delivered over a network: a teacher plays, a relay forwards, and
the student's LED strip and finger actuators fire from what the teacher
did. The three run as **separate processes** — a teacher, a student and a
relay have to be up at the same time, on different machines and holding
different devices — which is why this is the one launcher section whose
buttons start processes rather than sub-windows.

Six entries: **Relay Server**, **Teacher Client**, **Student Client**,
**Tele-training Setup Wizard**, **Network Latency Benchmark** and
**Remote Latency Analysis**. There is deliberately no shared settings
window: each of the three programs owns its own settings, because one
window showing all three roles' devices meant everyone was mostly looking
at settings that were not theirs.

To try it on one machine:

```bash
python -m server --init          # once: create the SQLite database
```

then start *Relay Server*, *Teacher Client* and *Student Client* from
section 8, in that order. Both clients arrive pre-filled with
`http://127.0.0.1:18765` and their demo account, so it is: sign in →
create/join a room → **Get ready** → **Ready for guidance** → **Start
teaching**.

### Where the tele-training documentation is

This section is orientation only. The module has two documents of its
own, and nothing here is repeated in them:

| Document | What it covers |
|---|---|
| **[REMOTE_GUIDANCE.md](REMOTE_GUIDANCE.md)** | The whole module. § 1–7 are the architecture: the three processes, the file map, the invariants that must not be broken (reaction-time origin, clock rules, what the relay may not do), the data flow of one live cue, the UI structure and the config schema. § 8–11 are running it, traps found the hard way, and known gaps. **§ 12 is the user-facing reference** — the setup wizard for a new machine, the guidance modes, what is reused from the local platform, provisional vs final results, which clock each timing measure is taken on, and the latency benchmark. |
| [server/README.md](server/README.md) | The relay as an operator guide: accounts and rooms, HTTP↔HTTPS and ws↔wss, JWT keys vs TLS certificates, deploying `server/` on its own, SQLite backup, and the full REST + WebSocket reference. |

Read REMOTE_GUIDANCE.md before changing anything under `remote_guidance/`
or `server/`.

## Haptic actuator configuration

Which vibration actuator the rig drives — and how hard — is **one setting
for the whole project**, stored in `config.json` and edited in the
launcher's **1. Initial Setup → Haptic Actuator Defaults**. No script,
window or experiment carries its own copy of "224 Hz / amp 64".

### Schema

```json
"haptic": {
  "using": "lra",
  "lra": { "default_frequency": 224, "default_amp": 64 },
  "erm": { "default_frequency": 1000, "default_amp": 50 }
}
```

| Field | Meaning | Default |
|---|---|---|
| `haptic.using` | Which actuator the platform drives by default — `"lra"` or `"erm"` (case-insensitive on load, stored lower case). | `"lra"` |
| `haptic.lra.default_frequency` | LRA drive frequency in Hz. | `224` |
| `haptic.lra.default_amp` | LRA drive amp (firmware PWM duty byte). | `64` |
| `haptic.erm.default_frequency` | ERM PWM **carrier** frequency in Hz. | `1000` |
| `haptic.erm.default_amp` | ERM drive amp. | `50` |

**The two frequencies do not mean the same thing.** An LRA's frequency is
a real mechanical drive frequency: the actuator only vibrates properly at
(or very near) its resonance, which is why
`validation_experiments/lra_resonance_intensity_calibration/` exists to
measure it. An ERM's frequency is the **PWM carrier** that chops its
drive rail — it is *not* the rotor's mechanical vibration frequency,
which follows the motor's speed and therefore the amp. The carrier only
has to be fast enough that the chopped drive behaves like smooth DC; too
low and the rotor cannot overcome stiction and never starts at all.

### Valid ranges

Enforced in one place (`common/haptic_config.py`) and used unchanged by
the Initial Setup spin boxes, so a control can never offer a value the
config would reject.

| Setting | Range | Where it comes from |
|---|---|---|
| amp (both actuators) | 0–255 | The firmware's PWM duty byte: `handlePulse()` rejects anything outside 0–255 (`teensy_driver/motor_driver.cpp`). |
| LRA frequency | 50–1000 Hz | Firmware `FREQ_MIN` = 50 Hz; the upper bound is the project's own LRA band (the Haptic Motor Bench's high-precision slider), and the resonance sweep only covers 100–350 Hz. |
| ERM frequency | 50–20000 Hz | Firmware `FREQ_MIN`/`FREQ_MAX` — the `F` command silently drops anything outside them. The project drives ERMs at 1–5 kHz. |

A frequency that is legal but unusual for that actuator (an LRA far off
resonance, an ERM carrier below ~1 kHz) is still accepted — this is a
research rig — but the Initial Setup window says so in an advisory note.

### What changing it affects

* the haptic quiz cue (`app/haptic_cue.py`) — amp **and** the PWM
  frequency it tunes each finger port to on connect;
* Haptic Vibrator Test and Haptic Motor Bench (their opening
  frequency/amp and "restore defaults");
* **Test Buzz** in every validation window, and the frequency pushed to
  the port before the pulse;
* Motor → ACC Delay: the actuator it opens on, and its motor port, PWM
  frequency and drive amp;
* Actuator Spectrogram: the type it opens on and its motor port;
* LRA Amplitude Sweep: the PWM frequency the amps are measured at;
* Adhesion Vibration Comparison: the frequency **and** amp it drives —
  always read from `haptic.lra` (even when `using` is `erm`) and shown
  read-only, so all three adhesives get an identical drive;
* the descriptions, tooltips and status lines of section 10 — they quote
  the configured numbers, not literals;
* the Wiring Guide's pin table (which actuator is in use, on which port).

### Priority: config defaults vs. what you type

The config supplies **initial values**; the operator always wins.

* A window reads the config when it **opens** and fills its controls.
* Anything typed afterwards is used for that run — the config is **never**
  re-applied at Start.
* Sweeps are unaffected in principle: the LRA resonance sweep still
  covers its whole 100–350 Hz range (finding the resonance is its
  purpose), the amplitude sweep still steps its own amp values, and the
  spectrogram still drives the ranges shown in its controls.
* Saved runs are immutable: a run's `meta.json` records what was actually
  sent to the hardware, and re-rendering an old chart uses **that**
  meta's parameters, never today's config. Runs saved before a field
  existed fall back to fixed historical constants, not to the config.
* New runs additionally record a `haptic_config` block: the config
  snapshot at run time, plus whether the amp / frequency / motor port
  used was the configured default or a manual override.

### Editing it

Initial Setup → **Haptic Actuator Defaults**: a radio pair for the
actuator in use plus a frequency and amp box for each actuator. Every
change is written to `config.json` **as you type** — no Save button and
no restart. Windows opened afterwards read the new values; validation
windows already open refresh their descriptive text (their controls are
left as the user set them).

Saving is read-modify-write and atomic (temp file + `os.replace`), so
every other key in `config.json` is preserved byte for byte and an
interrupted write can never leave unparseable JSON behind.

### Old config files

* No `haptic` key at all → the built-in defaults above are used; nothing
  is written until something saves.
* Some fields missing → only the missing ones fall back; the present ones
  are kept exactly.
* A malformed or out-of-range value → clamped into range (or, if it is
  not a number at all, replaced by the built-in default), with the
  correction reported in the log and shown in the Initial Setup window.
  Nothing out of range is ever sent to the hardware, and no correction is
  silent.

### What is deliberately *not* in this config

* **Motor port.** Which port an actuator is wired to (LRA → 11, ERM → 10)
  is a fact about the board, not a preference. The mapping is centralised
  in `common/haptic_config.py` (`ACTUATOR_MOTOR_PORTS`) so every window
  and experiment agrees on it, it is displayed in the Wiring Guide and in
  the Initial Setup summary, and every experiment window still has its
  own motor-port control that overrides it.
* **The firmware's boot PWM frequency** (224 Hz,
  `motor_driver.cpp DEFAULT_PWM_FREQ`). Experiments restore it on the
  port when they finish, so it must keep matching the firmware even if
  the configured LRA default changes.

---

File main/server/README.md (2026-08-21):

# Remote Guidance relay server

Routes key/finger guidance between a teacher client and a student client,
stores what happened, and answers latency probes. It is the only part of
the tele-training module that is not on a desk with hardware attached.

**Nothing here touches hardware.** This package imports no camera, MIDI,
MediaPipe, LED or haptic module - all of that runs on a client machine,
because the point of the relay is to move small JSON events, not to hold
devices. It also never re-runs finger matching and never computes its own
accuracy: the numbers it stores are the ones the student's own scoring
(`app.finger_matching`, `app.quiz.summarize`) produced, so the system has
exactly one definition of "correct".

---

## 1. Run it locally

From `main/` (the folder that contains `server/`):

```bash
python -m server --init
```

That writes `server/server_config.json`, creates the SQLite database, and
generates the JWT signing key pair. Then:

```bash
python -m server
```

The relay listens on `http://127.0.0.1:18765` by default (the clients
default to the same address; changing one means changing
`remote_guidance.config.NetworkConfig.server_url` and
`LocalServerConfig.port` too - a test asserts the three agree). Check it:

```bash
curl http://127.0.0.1:18765/api/v1/health
```

Other forms:

```bash
python -m server --gui
```

```bash
python -m server --host 0.0.0.0 --port 18765
```

Interactive API docs (FastAPI's own OpenAPI page) are at `/docs`.

### GUI vs CLI

`--gui` opens a Qt window (the launcher calls it simply **Relay Server**)
showing the bind host, port, registration state, database path, the HTTP
and WebSocket URLs, TLS on/off and run state, plus Start/Stop, the rooms
and clients currently connected, and the live server log.

Everything on that page is read-only. The editable settings - bind host,
port, whether registration is open, and the two token lifetimes - are
behind one **Settings** button, which writes `server_config.json`. It is
refused while the server is running, because the child process read its
configuration when it started; stop it first. TLS certificates and the
JWT signing keys stay out of that form deliberately: they are files, set
up once with `server/tools/`, and a text box inviting them to be retyped
would mostly produce a relay that cannot sign a token.

The panel does **not** run the server inside itself. It launches
`python -m server` as a separate process through `QProcess`, so Stop can
actually end it (terminate, then kill if it ignores that) and the port is
reliably released. Room/client rows come from the child process's own log
lines, which this window owns - no extra unauthenticated status endpoint
is exposed just to fill a dashboard.

The main panel opens at a compact **440 × 360 px**, also its minimum
size. The complete dashboard is wrapped in a resizable scroll area,
so server details, every button, the rooms/client tree and the server log
remain available without the window occupying most of a laptop screen.
The tree and log keep their own scroll bars as well.

The CLI form is what a headless deployment uses; the GUI is a convenience
for running the whole stack on one desk.

---

## 2. Accounts, rooms, joining

```bash
# teacher account
curl -X POST http://127.0.0.1:18765/api/v1/auth/register \
  -H 'Content-Type: application/json' \
  -d '{"username":"teacher1","password":"choose-a-long-one","role":"teacher"}'
```

```bash
# student account
curl -X POST http://127.0.0.1:18765/api/v1/auth/register \
  -H 'Content-Type: application/json' \
  -d '{"username":"student1","password":"choose-a-long-one","role":"student"}'
```

The response carries an access token and a refresh token.

A **teacher** creates a room and gets back a short join code:

```bash
curl -X POST http://127.0.0.1:18765/api/v1/rooms \
  -H "Authorization: Bearer $ACCESS" -H 'Content-Type: application/json' \
  -d '{"name":"Tuesday lesson"}'
```

A **student** joins with that code:

```bash
curl -X POST http://127.0.0.1:18765/api/v1/rooms/join \
  -H "Authorization: Bearer $ACCESS" -H 'Content-Type: application/json' \
  -d '{"join_code":"K7M4PQ"}'
```

Both clients have a form for this, so the curl calls above are only
needed for scripting or first-time setup. That form asks for a **join
code and nothing else** - no room id is ever typed into a client - and
the teacher reopens an existing room through this same `/rooms/join`
endpoint, which returns a room to its own owner without adding a
membership row. Keep that behaviour: it is what lets one field serve
both roles.

### The demo accounts

For development on one machine the clients' sign-in form arrives
pre-filled with `demoteacher` / `demostudent`. They are ordinary
accounts - register them once, on this relay, exactly as above:

```bash
curl -X POST http://127.0.0.1:18765/api/v1/auth/register \
  -H 'Content-Type: application/json' \
  -d '{"username":"demoteacher","password":"<the demo password>","role":"teacher"}'
```

The password each client fills in is the constant `DEMO_ACCOUNTS` in
`remote_guidance/gui_common.py`; nothing on this side knows or special-
cases those names, and the relay treats them like any other account. For
a real deployment, register proper accounts, set
`"allow_registration": false`, and empty that mapping so no password is
pre-filled.

Set `"allow_registration": false` once the accounts exist. The very first
account on an empty database is always allowed through, so that setting
cannot lock an operator out of a fresh install.

### Who may do what

Every REST call and every WebSocket frame is checked against the caller's
role *and* their membership row for that room:

- a teacher can only drive rooms they own - not another teacher's;
- a student can never send a teacher-only control
  (`guidance.live`, `session.*`, `recording.start/pause/stop`,
  `latency.probe`); the frame is refused and not relayed;
- a non-member gets 403 on the room's REST endpoints and is disconnected
  from its WebSocket before being registered.

The first version routes one teacher plus one active student per room.
The `room_members` table is already keyed by `(room_id, user_id)` with a
per-row role, so adding more students later is a routing change, not a
schema migration.

---

## 3. Configuring the clients

The clients are configured from the *root* `config.json` of the platform
(`main/config.json`), under a `remote_guidance` block - not from this
folder. Each client edits its own half from its own **Settings** button
(the student client shows the student's camera/MIDI/profile, the teacher
client the teacher's - neither sees the other's, and the launcher has no
settings window for them). This relay's own settings - bind host, port,
registration, token lifetimes - are the **Settings** button on the
control panel here, which writes `server_config.json`. Or edit the client
block by hand:

Each client Settings dialog can also take a one-shot camera photograph
and display the selected keyboard profile's colored pixel mask over it in
a separate preview window. It uses the form's current, possibly unsaved
camera/profile values and saves neither the picture nor the form. A
resolution mismatch is reported rather than resized into a false-looking
alignment. It is the same check the platform's quiz windows offer as
**Preview keyboard profile** (`app/gui/profile_preview.py`), so "is this
camera still aligned with the calibration?" is answered the same way
wherever it is asked.

This Settings dialog is also the only MIDI port selector for its role.
The student and teacher Session pages read the saved port directly and
do not repeat a MIDI dropdown or Refresh button. The teacher keeps a
manual **Connect MIDI** action beside **Chord detection** on its single
live-control row. There is no student-guidance selector on that row:
`visual` / `haptic` / `both` is selected by the student client on its own
Session page.

Teacher and student usually run the same model of keyboard, which reports
the same port name twice. The picker lists those as `... #1` / `... #2`,
numbered in the order the machine enumerates them, and warns that the
numbering can change when a keyboard is replugged. Give the two roles
different ones - identical values silently point both clients at one
instrument. See [../REMOTE_GUIDANCE.md](../REMOTE_GUIDANCE.md) §9.8.

```json
"remote_guidance": {
  "network": {
    "server_url": "http://127.0.0.1:18765",
    "verify_tls": true
  },
  "student": {
    "camera": {"index": 0, "width": 1280, "height": 720, "fps": 30},
    "midi": {"port_name": "SE25 MIDI1 #1"},
    "keyboard_profile": "white-city-lab-20260717",
    "led": {"port": "/dev/tty.usbmodem1101"},
    "haptic": {"port": "/dev/tty.usbmodem2201"},
    "default_guidance_mode": "both"
  },
  "teacher": {
    "camera": {"index": 1},
    "midi": {"port_name": "SE25 MIDI1 #2"},
    "keyboard_profile": "teacher-desk-20260801"
  }
}
```

Student and teacher each have their **own** camera, MIDI port and
keyboard profile; neither touches the shared `camera`/`midi`/
`active_keyboard_profile` keys the ordinary (non-remote) tools use.

The student's LED strip and haptic rig are both serial devices. Blank
ports use auto-detection; `student.led.port` and `student.haptic.port`
remain config-only overrides for a machine where the two similar boards
are detected incorrectly. Setting both overrides to the same port is
rejected with a clear error.

**No credentials live in `config.json`.** Usernames, passwords, tokens
and TLS private keys are never written there.

---

## 4. HTTP/ws → HTTPS/wss

Development default is plain `http` + `ws` on localhost.

**Recommended for anything real:** leave the relay on plain HTTP bound to
localhost and put a reverse proxy in front that terminates TLS. Caddy
obtains and renews a real certificate on its own:

```
relay.example.ac.uk {
    reverse_proxy 127.0.0.1:18765
}
```

Nginx equivalent (the two `Upgrade` headers are what keeps the WebSocket
working through the proxy):

```nginx
server {
    listen 443 ssl;
    server_name relay.example.ac.uk;
    ssl_certificate     /etc/letsencrypt/live/relay.example.ac.uk/fullchain.pem;
    ssl_certificate_key /etc/letsencrypt/live/relay.example.ac.uk/privkey.pem;

    location / {
        proxy_pass http://127.0.0.1:18765;
        proxy_http_version 1.1;
        proxy_set_header Upgrade $http_upgrade;
        proxy_set_header Connection "upgrade";
        proxy_set_header Host $host;
        proxy_read_timeout 3600s;
    }
}
```

Clients then use `https://relay.example.ac.uk` as their server URL; the
WebSocket URL is derived from it automatically (`wss://`).

**Direct TLS**, if you do not want a proxy: generate a development
certificate

```bash
python -m server.tools.generate_dev_certificate --host 127.0.0.1
```

then set in `server_config.json`:

```json
"tls": {"enabled": true, "certfile": "secrets/dev_cert.pem", "keyfile": "secrets/dev_key.pem"}
```

A self-signed certificate makes clients refuse the connection until it is
trusted, which is why it is never enabled by default.

### JWT keys are not the TLS certificate

Two different key pairs, two different jobs, and they are not
interchangeable:

| | JWT signing keys | TLS certificate |
|---|---|---|
| Files | `secrets/jwt_private.pem`, `secrets/jwt_public.pem` | e.g. `secrets/dev_cert.pem`, `secrets/dev_key.pem` |
| Created by | `python -m server.tools.generate_keys` (or `--init`) | `python -m server.tools.generate_dev_certificate`, or a CA / Caddy / certbot |
| Proves | that a token was issued by this server and has not been altered | that the *host* you connected to is the one you meant |
| Seen by | nobody outside the server; only the public half verifies | every client, during the handshake |
| Rotating it | logs everyone out (all tokens become unverifiable) | needs a client reconnect, tokens are unaffected |

A deployment behind Caddy/Nginx has JWT keys here and its TLS material in
the proxy. That is normal - the relay still signs tokens either way.

### Tokens and sessions

Access tokens last 30 days and refresh tokens 180 days by default
(configurable). That is deliberately long so a lesson series does not get
interrupted by a re-login, which makes revocation the important part:

- `POST /auth/logout` blacklists the presented access and refresh tokens
  by their `jti`;
- `POST /auth/refresh` rotates - the refresh token you present is spent,
  so a stolen copy stops working as soon as the real client refreshes;
- a revoked `jti` is rejected even while its `exp` is still in the future.

Server logs never contain a password or a whole token.

---

## 5. Deploying this folder on its own

`server/` has no dependency on the rest of the repository. To move it:

```bash
scp -r server/ user@host:/opt/remote-guidance/
```

```bash
ssh user@host
cd /opt/remote-guidance
python3 -m venv .venv && . .venv/bin/activate
pip install -r server/requirements.txt
python -m server --init
python -m server --host 0.0.0.0 --port 18765
```

Run it from the directory that *contains* `server/`, so `python -m
server` resolves. Note that `secrets/` and `server_config.json` are
git-ignored, so a fresh copy generates its own - which also means tokens
issued by the old host will not verify on the new one.

As a systemd unit:

```ini
[Unit]
Description=Remote Guidance relay
After=network.target

[Service]
WorkingDirectory=/opt/remote-guidance
ExecStart=/opt/remote-guidance/.venv/bin/python -m server --host 127.0.0.1 --port 18765
Restart=on-failure
User=relay

[Install]
WantedBy=multi-user.target
```

Bind to `127.0.0.1` when a proxy terminates TLS in front; bind to
`0.0.0.0` only when the relay itself is the edge.

---

## 6. Backing up SQLite

The database is `data/remote_guidance.db` (plus `-wal`/`-shm` sidecars,
because it runs in WAL mode). **Do not copy those three files while the
server is running** - use SQLite's own online backup, which is consistent
without stopping anything:

```bash
sqlite3 data/remote_guidance.db ".backup 'backup/relay-$(date +%F).db'"
```

Or from Python:

```bash
python -c "import sqlite3,sys; s=sqlite3.connect(sys.argv[1]); d=sqlite3.connect(sys.argv[2]); s.backup(d); d.close(); s.close()" \
  data/remote_guidance.db backup/relay.db
```

Restoring is just putting the file back and starting the server; the
schema version is checked and migrated forward on start (`PRAGMA
user_version`), so an older backup upgrades in place.

No video is ever stored in the database. Recordings hold the note/finger
event list needed to drive cues; the media stays on the machine that
captured it, so a backup stays small.

---

## 7. REST API

All paths are prefixed `/api/v1`. Everything except `/health`,
`/auth/register`, `/auth/login` and `/auth/refresh` needs
`Authorization: Bearer <access token>`.

| Method | Path | Who | What |
|---|---|---|---|
| GET | `/health` | anyone | liveness, protocol/schema version, room and connection counts |
| POST | `/auth/register` | anyone (if enabled) | create an account, returns a token pair |
| POST | `/auth/login` | anyone | token pair |
| POST | `/auth/refresh` | refresh token | new pair; the presented refresh token is spent |
| POST | `/auth/logout` | any user | revoke the presented access/refresh tokens |
| GET | `/auth/me` | any user | the caller's account |
| POST | `/rooms` | teacher | create a room, returns its join code |
| POST | `/rooms/join` | any user | join by code |
| GET | `/rooms/{room_id}` | member | room details |
| POST | `/rooms/{room_id}/close` | owning teacher | close the room |
| GET | `/rooms/{room_id}/members` | member | members + who is online now |
| POST | `/rooms/{room_id}/recordings` | owning teacher | upload a fingering/MIDI sequence (metadata + events, no video) |
| GET | `/rooms/{room_id}/recordings` | member | list them |
| GET | `/recordings/{recording_id}` | member | full event list - the student downloads this **before** playback |
| POST | `/rooms/{room_id}/sessions` | owning teacher | open a guidance session; the teacher does not select the student's rendering mode |
| GET | `/sessions` | any user | list the caller's sessions, newest first, with event counts |
| GET | `/sessions/export` | any user | every guidance + performance event of many sessions in one reply |
| GET | `/sessions/{session_id}` | member | session state |
| GET | `/sessions/{session_id}/events` | member | stored guidance + performance events |
| GET | `/sessions/{session_id}/summary` | member | counts, plus the student's own reported summary |

`/sessions/{id}/summary` returns the student's result under
`student_reported_summary` with `summary_source: "student"`. The naming
is deliberate: the server did not compute it.

### Getting a study's timing data off a deployed server

Every other session route needs a session id you already have. During a
lesson the clients do have it, but after the fact the ids only exist in
whatever each client wrote locally - the Student Client records the
session id in its `data/quiz/<session name>/meta.json` as
`song_name: "remote:<session id>"` - and a folder that was never copied
off the student machine leaves the matching server rows unreachable
without a shell on the box. `/sessions` and `/sessions/export` exist for
that case and do nothing else.

    # what is there
    GET /api/v1/sessions?since=<unix seconds>&limit=200
    # pull it
    GET /api/v1/sessions/export?since=<unix seconds>&limit=100
    GET /api/v1/sessions/export?session_ids=<id>,<id>,<id>

`/sessions` returns each session plus `guidance_event_count` and
`performance_event_count`, so a session that recorded nothing can be
skipped without a second request, and `truncated: true` when more matched
than `limit` allowed through. Both accept `room_id`, `since` and `state`;
`limit` caps at 1000 for the listing and 500 for the export, and asking
for more explicit `session_ids` than `limit` is a 400 rather than a
silent trim.

Authorisation is the same membership rule as the single-session routes,
applied through the same helper: a session in a room the caller never
joined is never listed, naming that room outright is a 403, and an
explicit `session_ids` entry from another teacher's room is a 403 rather
than a silent omission. Neither endpoint can write anything.

The export returns stored payloads verbatim - in particular the per-cue
`timings` dictionary the Student Client sends with each performance row
(`teacher_send_wall_ns`, `server_receive_wall_ns`,
`student_receive_wall_ns`, then the student's own monotonic
`queue_enter` / `cue_dispatch_start` / `led_command_complete` /
`haptic_command_complete` / `visual_painted` / `cue_ready` marks). Read
`timing_kind: "software_dispatch_render"` before using any of it: those
are dispatch and render moments on the student's machine, not physical
LED or actuator onset, and the wall-clock marks come from three different
machines' clocks. Section 9's caveats apply unchanged - the monotonic
marks may be subtracted from each other, the wall-clock ones may not.

The current teacher sends `{"mode": "live"}` when opening a live
session. Its initial `guidance_mode` is the neutral value
`student_choice`, not a visual/haptic default. Once the student is ready,
its session-bound `recording.ready` frame reports `visual`, `haptic` or
`both`; the background writer stores that student-reported value on the
session. Older clients may still send a concrete value in the REST body,
but the student's later ready message remains authoritative.

The Teacher Client's Recorded guidance tab follows the same ownership
rule. After uploading the selected song's note/finger events, Trigger
creates a separate session with `mode: "recording"`, `recording_id` and
`playback_mode` (and no teacher guidance modality), then sends
`session.start` followed by `recording.start`. It no longer creates or
borrows a live session merely to enable recorded playback. A student
that has not yet entered Ready state retains the one-shot
`recording.start` envelope locally and consumes it immediately after it
becomes ready.

A recording upload never writes to either client's song library. It
inserts a new uuid-keyed recording and event rows in SQLite, so uploading
the same named source again creates another relay record instead of
overwriting the previous one. The student consumes the downloaded event
list in memory; its performed-session files are written separately by
the client under `data/quiz/<session name>/`.

---

## 8. WebSocket

One persistent connection per client:

```
/ws/v1/rooms/{room_id}
```

The **first frame must be an `auth` envelope** carrying the access token
in its payload. The token is not put in the URL query string, where it
would end up in proxy logs and browser history. Membership of the room in
the path is checked before the connection is registered, so an
unauthenticated socket never receives another room's traffic.

Every frame is one JSON envelope:

```json
{
  "v": 1,
  "type": "guidance.live",
  "message_id": "8f14e45f-ceea-467a-9f0a-8b1e4a1c53d1",
  "room_id": "…",
  "session_id": "…",
  "seq": 42,
  "sent_at_unix_ns": 1786000000000000000,
  "payload": {}
}
```

The relay adds its own block and never rewrites `sent_at_unix_ns`:

```json
"server": {
  "receive_wall_ns": 1786000000001234000,
  "send_wall_ns":    1786000000001250000,
  "sender_user_id": "…", "sender_username": "…", "sender_role": "teacher",
  "out_of_order": false
}
```

Message types:

| Type | Sender | Meaning |
|---|---|---|
| `auth` | client → server | first frame; token in payload |
| `presence` | server → room | who is connected now |
| `heartbeat` | client ↔ server | keep-alive, echoed with server stamps |
| `guidance.live` | teacher | one or more `actions` (note + finger + probabilities) with a `timeout_s` |
| `guidance.received` | student | arrived; sent *before* any cue is presented |
| `guidance.presented` | student | local cue is ready, with the student's own dispatch timings |
| `performance.response` | student | what was actually played; `stage` is `provisional` or `final` |
| `session.start` / `pause` / `resume` / `stop` | teacher | session control |
| `session.finished` | student | end of session + the student's own summary |
| `recording.ready` | student | ready for guidance; reports the student's selected modality and enabled output channels |
| `recording.start` / `pause` / `stop` | teacher | remote trigger for that sequence |
| `latency.probe` | teacher | benchmark probe |
| `latency.received` | student | immediate ack - this is what transport RTT ends on |
| `latency.presented` | student | after the local cue dispatch completed |
| `latency.ack` | server → sender | the relay accepted and forwarded the probe (isolates the teacher→server hop) |
| `error` | server → sender | refused frame; `code` says why, `fatal` says whether the socket survives |

Robustness rules the relay enforces:

- frames larger than 64 KiB are rejected before being parsed;
- a repeated `message_id` is **not** relayed twice - the sender gets an
  `error` with code `duplicate_message` instead, so a reconnecting client
  replaying its outbox cannot double-cue the student;
- a `seq` that goes backwards is flagged `out_of_order` in the server
  block but still delivered, because dropping a late cue silently would
  be worse than showing it late;
- `room_id` in a frame must match the socket's room;
- a client may reconnect and re-authenticate at any time; heartbeats
  detect a dead path in between.

---

## 9. Latency benchmark

Run from `main/`:

```bash
python remote_latency_benchmark.py --server http://127.0.0.1:18765 \
  --username teacher1 --student-username student1
```

This default run is self-contained: the benchmark authenticates both
existing accounts, creates a temporary room, joins and connects its own
simulated Student WebSocket, reads the room's membership back from the
relay so the run shows both accounts really were in one room, then closes
the room without deleting its database record. Only the relay and
benchmark processes need to be open.

No room ever has to be created or pasted in by hand. `--external-student`
creates the room here as well, prints its join code for a real Student
Client, and waits (`--wait-for-student`, default 180 s) until a `presence`
frame shows a student in the room before it starts probing. Use it only
when a real Student Client and its UI/LED/haptic dispatch are
intentionally part of the measurement. `--room-id <id>` is for the single
case where that Student Client has already joined a room of its own.

Defaults follow the report's benchmark: **1000 probes at 500 ms
intervals over one persistent WebSocket per endpoint**, with warm-up samples
recorded separately and excluded from the statistics.

`--interval-mode` chooses how the probes are spaced. The default `fixed`
period is easy to describe but samples the same phase of anything
periodic in the path on every probe; `uniform` jitters each wait by
`--interval-jitter` of the interval, and `poisson` draws it from an
exponential distribution (RFC 2330 § 11.1, truncated at 5x the mean).
`human` paces probes like a person being cued. It is fitted at run time
to every trial of whichever participants are in `data/quiz/` (at 14
participants: median 664 ms, log-sigma 0.441 over 11,335 trials, ~0.7 s),
and samples hierarchically - a participant, then that participant's own
lognormal - because pooling every trial inflates sigma. The fitted median
is also its default interval. Lognormal is checked against ex-Gaussian
and shifted lognormal rather than assumed, and a bootstrap interval is
reported with it; the CLI prints progress while it reads. Each run
records the population it used in `summary.json`. The first three modes
share one mean, so only the spacing pattern changes; `human` has its own
median and a mean above it. The pacing seed is recorded in
`summary.json` and can be replayed with `--interval-seed`. Results land in
`data/remote_guidance/latency/<run_id>/` as `samples.csv`,
`summary.json` and `latency.png`.

### What is measured

| Metric | Definition |
|---|---|
| **Transport RTT** | teacher's `perf_counter_ns` at probe send → same clock when `latency.received` arrives. **Primary metric.** |
| Teacher→server ack | probe send → the relay's `latency.ack`. Isolates which hop is slow. |
| Cue-presented RTT | external-Student mode only: probe send → `latency.presented`, including real Student local cue dispatch |
| Student dispatch duration | external-Student mode only: measured entirely on the real Student's monotonic clock |
| One-way estimate | see below |
| Loss | probes with no valid ack before the timeout, as a proportion of the run |

Reported for each: n, lost, loss rate, min, mean, standard deviation,
median, p95, p99, max.

### Why cross-machine timestamps are not one-way latency

`T_receive,B − T_send,A` is only a latency if A's and B's clocks agree.
Two independent computers do not: their wall clocks differ by an unknown
offset that is often larger than the delay being measured, so the
subtraction can even come out negative. The tool therefore:

- reports **RTT as the primary transport measure**, since both stamps
  come from one clock on one machine and no synchronisation is needed;
- reports a one-way figure **only** when both ends are NTP-synchronised
  and the estimated offset uncertainty is recorded alongside it;
- otherwise shows `RTT/2`, labelled explicitly as a *symmetry-based
  estimate* - which assumes the two directions are equally fast, and they
  often are not.

A lightweight four-timestamp offset estimator (many exchanges, lowest-RTT
samples preferred, uncertainty retained) is included so the assumption
can at least be quantified. It is **not** NTP and is not presented as a
substitute for it; `time.is` or `chronyc tracking` before a run remains
the sanity check.

Monotonic timestamps are never subtracted across machines. They are used
only on the machine that produced them, and travel as opaque values
otherwise.

### Software timing, not physical onset

Everything above is **software dispatch/render timing**: the moment a
command was written and flushed, or a frame was painted. It is not the
moment an LED emitted light or a motor started moving. Measuring physical
onset needs a photodiode on the key and an accelerometer on the actuator
sampled on one acquisition clock (the report's
`System Transmission Performance Benchmarking`); the schema keeps fields
free for that, and this tool does not claim it.

### Why student reaction time does not start at the teacher's send time

Student reaction time is always

```
reaction_time_ns = student_response_monotonic_ns - cue_ready_monotonic_ns
```

Both terms come from the student's own monotonic clock. `cue_ready` is
the moment the student's cue was actually ready - the maximum of the LED
command completing, the screen paint finishing, and the haptic serial
flush returning, over whichever channels that session enabled.

Starting the clock at `teacher_send`, `server_receive` or
`student_receive` would fold network delay, queueing and local dispatch
into a number describing a *person*, so a slow network would look like a
slow learner. Those transport figures are all recorded, separately, on
the same event - they are simply never part of the reaction time.

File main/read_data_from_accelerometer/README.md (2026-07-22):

# read_data_from_accelerometer - legacy LIS3DH reader

Early standalone accelerometer tooling, kept as reference. These files
predate the unified haptic-piano firmware (`teensy_driver/`): the
bundled sketch bit-bangs SPI to a single LIS3DH and prints bare
`x,y,z` lines, and the two Python scripts parse exactly that format.

| File | Purpose |
|---|---|
| `read_data_from_accelerometer.ino` | Old standalone Teensy sketch: software-SPI LIS3DH readout, prints `x,y,z` per sample. Superseded by `teensy_driver/accel_driver.cpp`. |
| `plot_lis3dh.py` | Live matplotlib X/Y/Z plot of those `x,y,z` lines. |
| `read_serial_live.py` | Raw serial line printer (debug). |

**For the current rig, use the launcher instead**: section
"2. Feature Testing" → **Accelerometer Live View**
(`app/gui/accelerometer_window.py`). It speaks the current firmware
protocol (`A START <ms>` / `ACC,<id>,x,y,z`, firmware >= v2.5.0),
lets you pick which sensor id to follow (persisted to `config.json`
as `accelerometer.sensor_id`, also the default sensor in the
validation sweep windows), and runs the serial I/O off the GUI thread.
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

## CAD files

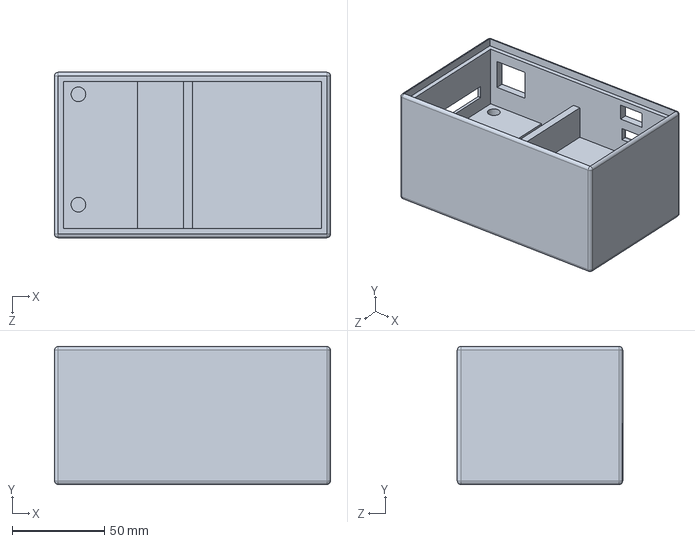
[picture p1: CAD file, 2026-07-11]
3d_model/main.SLDPRT
150.0 x 75.0 x 90.0 mm

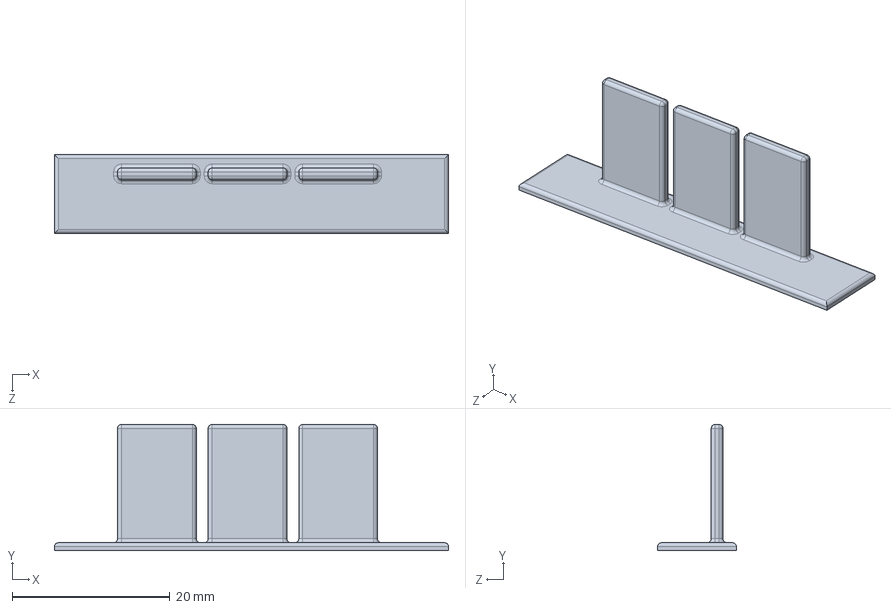
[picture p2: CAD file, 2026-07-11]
3d_model/board-support.SLDPRT
50.0 x 16.0 x 10.0 mm

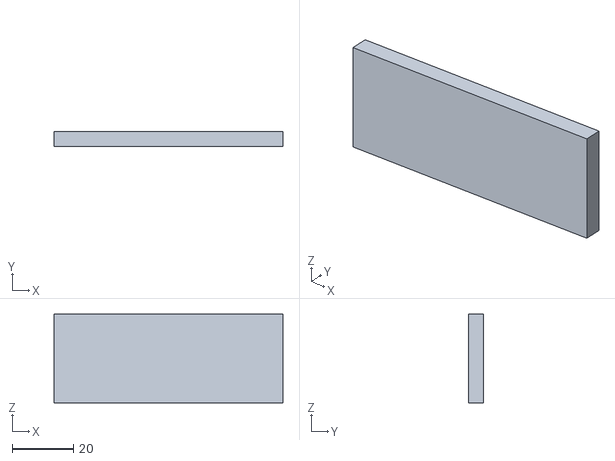
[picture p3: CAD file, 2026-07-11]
3d_model/Battery-Cover.STL
75.0 x 5.00 x 29.0

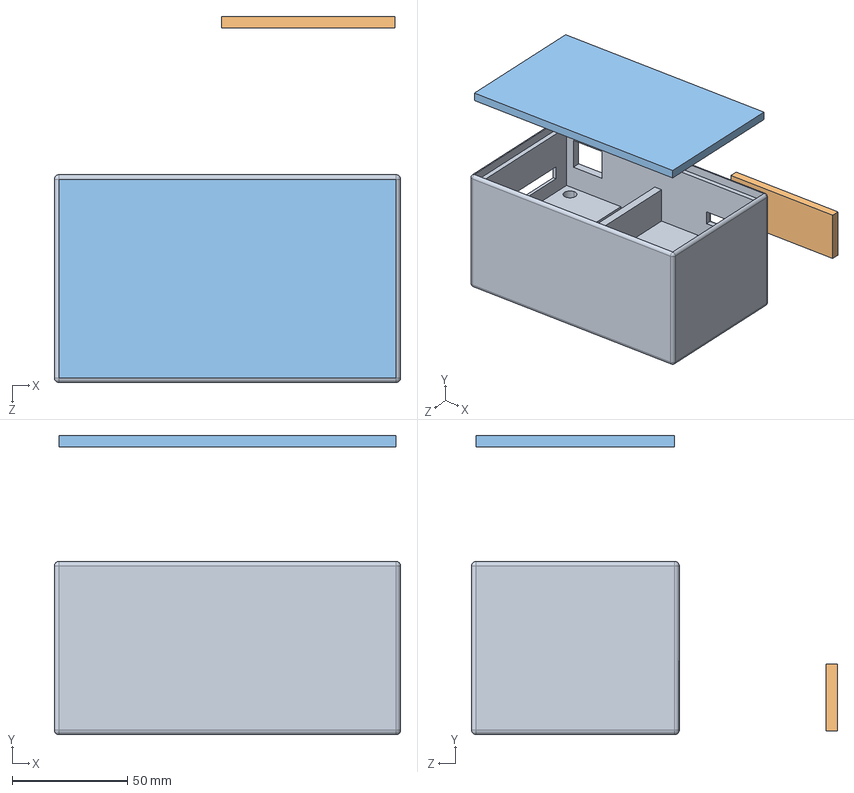
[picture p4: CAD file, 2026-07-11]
3d_model/assm.STEP
150.0 x 129.6 x 158.5 mm
零件1
电池盖子
顶盖

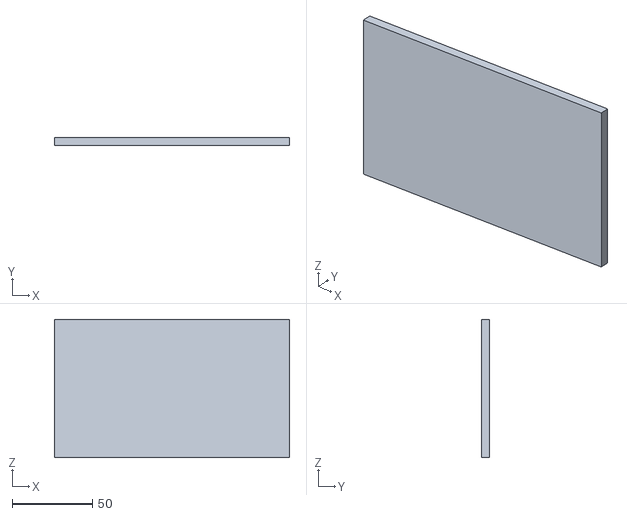
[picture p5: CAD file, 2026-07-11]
3d_model/cover.STL
146.0 x 5.00 x 86.0

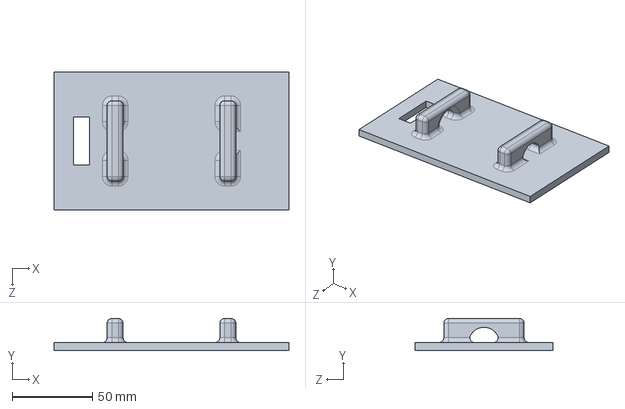
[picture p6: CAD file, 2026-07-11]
3d_model/top_cover.SLDPRT
146.0 x 20.0 x 86.0 mm

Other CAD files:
3d_model/电池盖子.SLDPRT
3d_model/assm.SLDASM
3d_model/board-support.STL
3d_model/main.STL
3d_model/top_cover.STL

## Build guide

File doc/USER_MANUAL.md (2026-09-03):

# Multi-Modal Platform — User Manual

A screenshot-led walkthrough of every window the launcher opens, in the order
it lists them. The software itself is in `main/`; run it with
`cd main && python launcher.py`.

This manual answers **what a window is for, when you open it, and what you
click**. It does not repeat the design rationale, the algorithms or the study
protocols — those live in [`doc/PLATFORM.md`](PLATFORM.md),
[`doc/SEQUENCE_GENERATOR_ALGORITHM.md`](SEQUENCE_GENERATOR_ALGORITHM.md),
[`doc/REMOTE_GUIDANCE.md`](REMOTE_GUIDANCE.md) and
[`doc/RHYTHM_EXPERIMENT.md`](RHYTHM_EXPERIMENT.md), and are linked from each
section below.

> **About the screenshots.** Every image is the real tool, not a mock-up. Each
> was rendered offscreen **on macOS**, against a copy of the project, so no
> live data was touched. The platform also runs on Windows, where these same
> tools carry native Windows chrome around identical contents.
>
> The camera in each preview is a frame from a recorded study trial
> (`main/data/quiz/P18-T25-Cγ/`) standing in for a live feed. It has to be a
> recording made through the camera position the active profile was calibrated
> against — anything else and the key masks would photograph visibly offset
> from the keys they belong to. The serial and MIDI ports shown are
> placeholders; on your machine those pickers list your own hardware, and the
> Accelerometer Live View is replaying a saved run
> (`main/data/validation_experiments/motor_acc_delay_experiment/`) in place of
> a live rig.

---

## Contents

| # | Section | What it is for |
|---|---|---|
| — | [Before you start](#before-you-start) | Install, launch, and the three window lifetimes |
| — | [The launcher](#the-launcher) | The hub window |
| 1 | [Initial Setup](#1-initial-setup) | Wire the rig, calibrate the camera, choose cue styles — run once per setup |
| 2 | [Feature Testing](#2-feature-testing) | Prove each piece of hardware works |
| 3 | [Recording & Playback](#3-recording--playback) | Record a song with fingering, replay it |
| 4 | [Experiment Sequence Design](#4-experiment-sequence-design) | Generate and inspect the main study's stimuli |
| 5 | [Practice & Assessment](#5-practice--assessment) | Run a single cue-response quiz |
| 6 | [Main User Study](#6-main-user-study) | Schedule and run a participant's 27 trials |
| 7 | [Data Analysis](#7-data-analysis) | Score trials, then analyse one participant, the group, and a model |
| 8 | [Tele-training](#8-tele-training) | Teacher, relay and student over a network |
| 9 | [Tools](#9-tools) | Housekeeping on collected data |
| 10 | [Validation Experiments](#10-validation-experiments) | Small hardware-characterisation sweeps |
| 11 | [Rhythm Experiment](#11-rhythm-experiment) | The separate cue-withdrawal study |
| 12 | [Demo & About](#12-demo--about) | Screenshot helper and front matter |
| — | [Where files are written](#where-files-are-written) | One table of every output path |

---

## Before you start

### Install and launch

The platform is tested on **macOS** and **Windows**, and there are two ways in.

**Windows — the bundled package.** Download the archive from the repository's
[Releases](https://github.com/shengj1ang/nail-haptic-piano-platform/releases),
unpack it, and double-click `main\launcher.bat`. Nothing has to be installed:
the bundle carries its own Python 3.11 under `main\runtime\Python311\`, and
the `.bat` puts it on the PATH for that window only.

**From source, on either platform.** Everything runs in one Python environment
(the project calls it `fingercam`):

```bash
pip install -r requirements.txt
python launcher.py
```

MediaPipe's hand model, `hand_landmarker.task`, is already bundled in this
folder, so there is nothing else to download.

Every tool also runs standalone from its own entry-point script
(`python student_quiz.py`, `python music_playback.py`, and so on) — the
launcher opens the exact same window classes, so nothing behaves differently
depending on how you started it.

`config.json` is created on first run. It holds the camera, the MIDI port
name, which keyboard profile is active, the visual cue style, the haptic
actuator defaults and the tele-training block. Several windows in section 1
write to it; almost nothing else does.

### The three window lifetimes

Hover any launcher button and it tells you which of these it is:

| Lifetime | Which buttons | Behaviour |
|---|---|---|
| **Exclusive** | most of the list | Opening another tool closes this one first. Most of these claim the camera or the MIDI keyboard, and two at once would fight over the device. Closes with the launcher. |
| **Concurrent** | the three Analysis windows, the two Tools windows, About | Claims no hardware, so it stays open beside an exclusive tool. Pressing the button again raises the window you already have instead of starting a second copy. Closes with the launcher. |
| **Independent process** | Relay Server, Teacher Client, Student Client, Network Latency Benchmark (section 8) | Starts its own process. A relay, a teacher and a student are meant to run at the same time, so nothing in the launcher closes these — and they keep running after the launcher quits. Stop them from their own windows. |

---

## The launcher

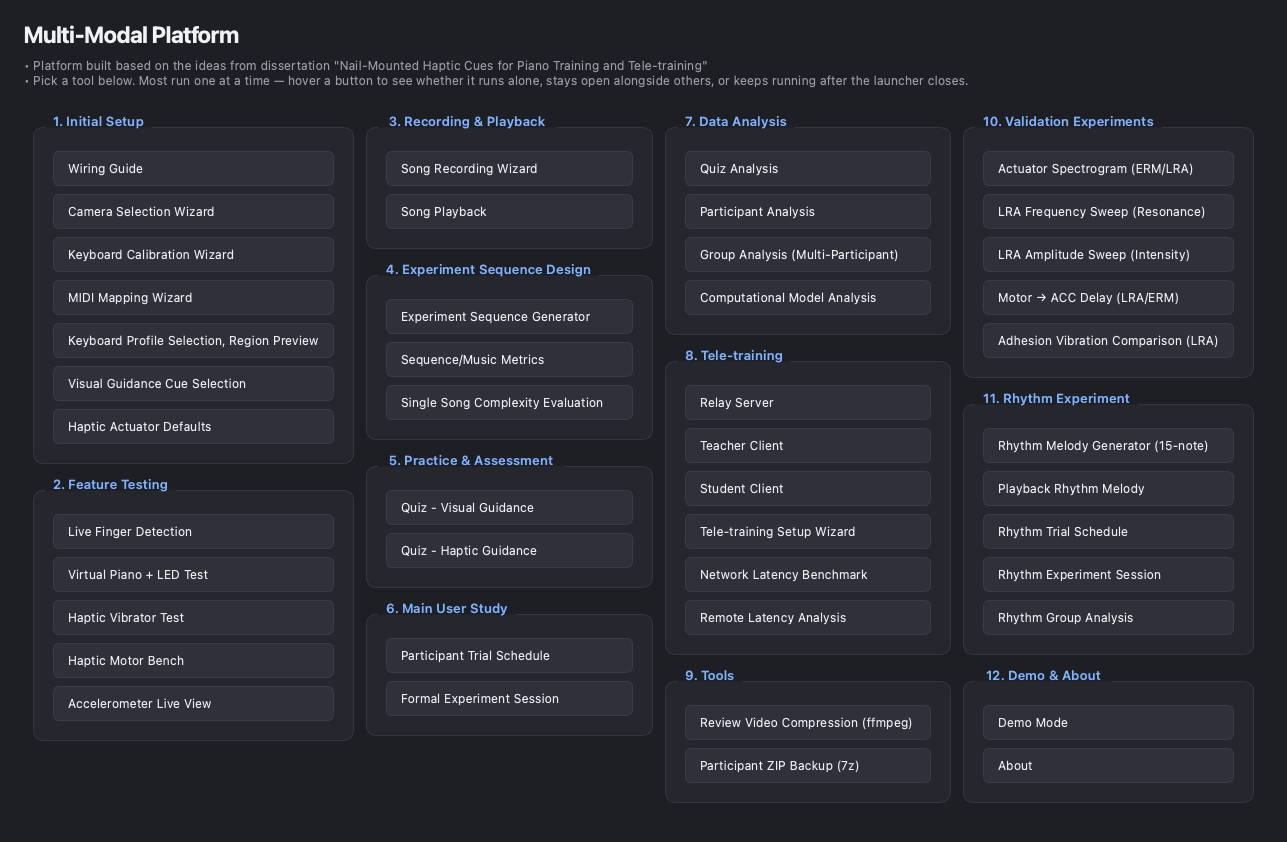
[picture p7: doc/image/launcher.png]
The launcher hub


One button per tool, grouped into the numbered sections this manual follows. The grid chooses its own column count to fit your screen, so on a
narrower display you will see fewer columns and a vertical scrollbar rather
than a window running off the edge.

Nothing here holds any hardware itself — it only opens the tool you click.

---

## 1. Initial Setup

Run-once work: wire the rig, tell the platform which camera and keyboard it
has, and pick the cue styles. Everything else in the platform reads what you
set here.

Do them in the order the buttons are listed — the calibration wizard needs a
working camera, and the MIDI mapping wizard needs a calibrated profile.

### 1.1 Wiring Guide

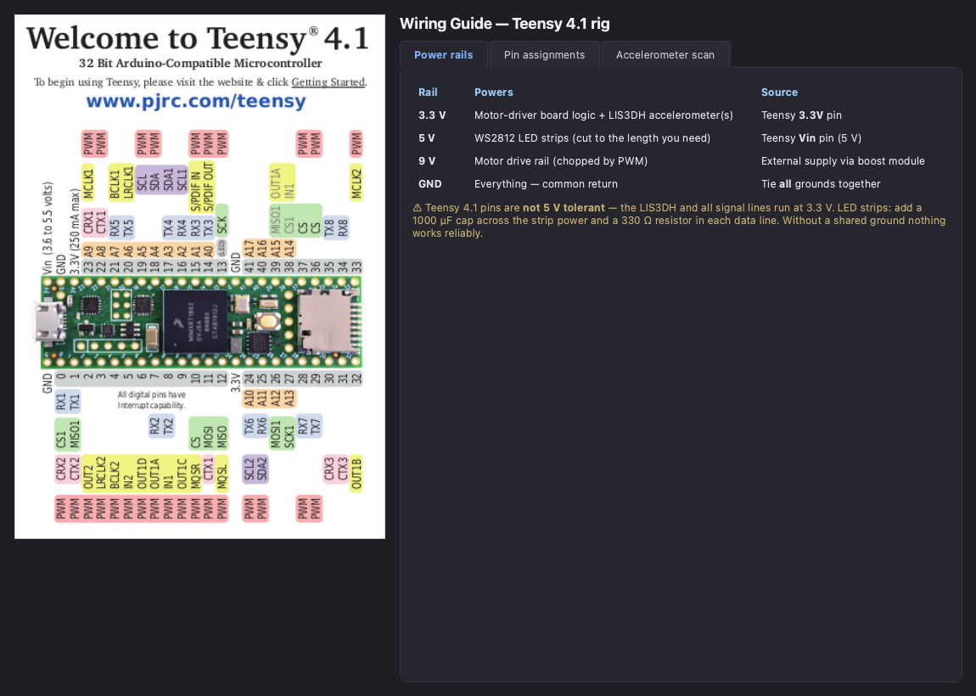
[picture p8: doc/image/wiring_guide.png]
Wiring Guide


A single reference for wiring the whole rig to the Teensy 4.1: the power
rails, the pin assignments for the finger motors, the two WS2812 LED strips
and the LIS3DH accelerometer bus, next to a labelled board pinout so the pin
numbers map straight onto the physical header. The content mirrors the
*Current Wiring* table in `doc/firmware.md`, which stays the source
of truth.

Three tabs:

| Tab | Contents | |
|---|---|---|
| Power rails | 3.3 V / 5 V / 9 V / GND and what each one feeds | [screenshot](image/wiring_guide_tab1-power-rails.png) |
| Pin assignments | Motor, LED-strip and accelerometer pins on the board diagram | [screenshot](image/wiring_guide_tab2-pin-assignments.png) |
| Accelerometer scan | The one interactive part — see below | [screenshot](image/wiring_guide_tab3-accelerometer-scan.png) |

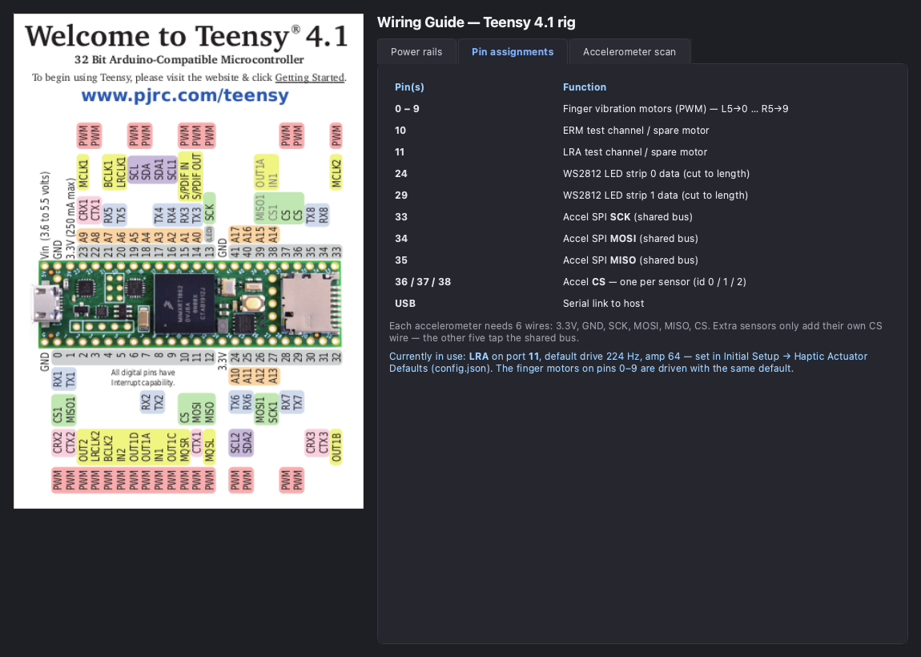
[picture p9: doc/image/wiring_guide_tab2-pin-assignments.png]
Wiring Guide — pin assignments


**The accelerometer wiring scan.** The four accelerometer bus wires (SCK /
MOSI / MISO / CS) are easy to swap by accident, and a wrong order just reads
back `0xFF` with no hint which wire is where. Plug the sensor's four wires
onto pins 33/34/35/36 in **any** order and press **A SCAN** (firmware
v2.10.0 or newer): it tries all 24 role permutations and reports the one that
answers `WHO_AM_I = 0x33`.

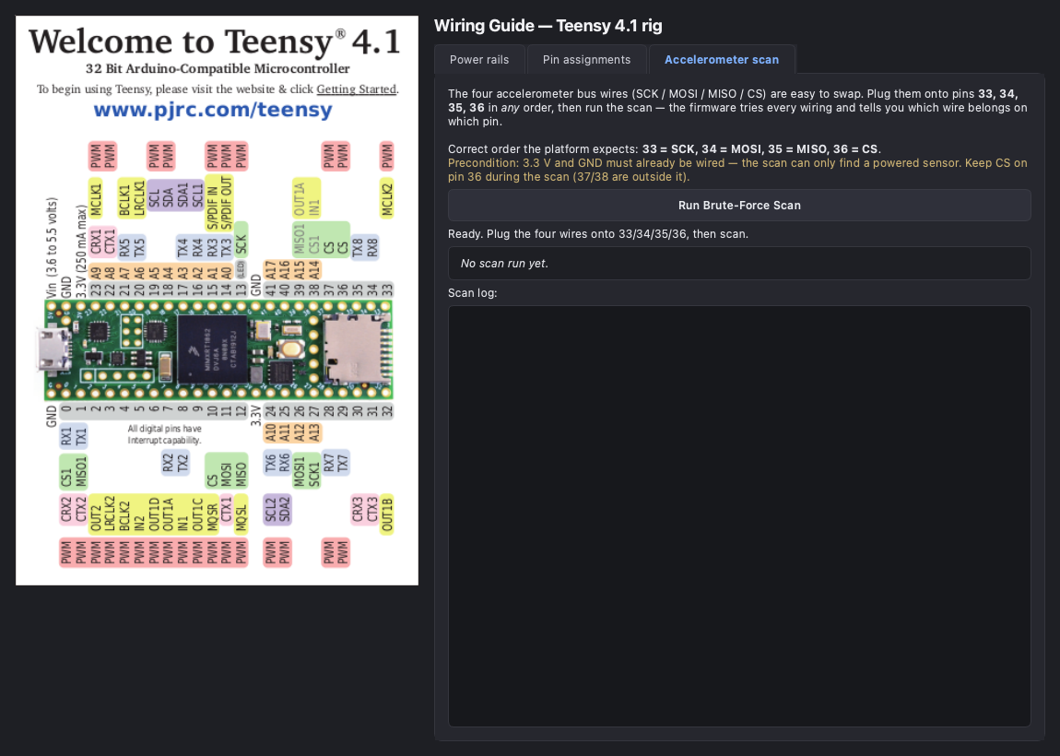
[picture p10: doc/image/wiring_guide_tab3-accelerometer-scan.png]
Wiring Guide — accelerometer scan


The scan is read-only diagnostics. The firmware restores the normal bus state
when it finishes and never changes the running pin mapping, so the standard
wiring (33 = SCK, 34 = MOSI, 35 = MISO, 36 = CS) stays what the rest of the
platform expects. It only works once 3.3 V and GND are correct, so a
successful scan doubles as proof the sensor is powered.

### 1.2 Camera Selection Wizard

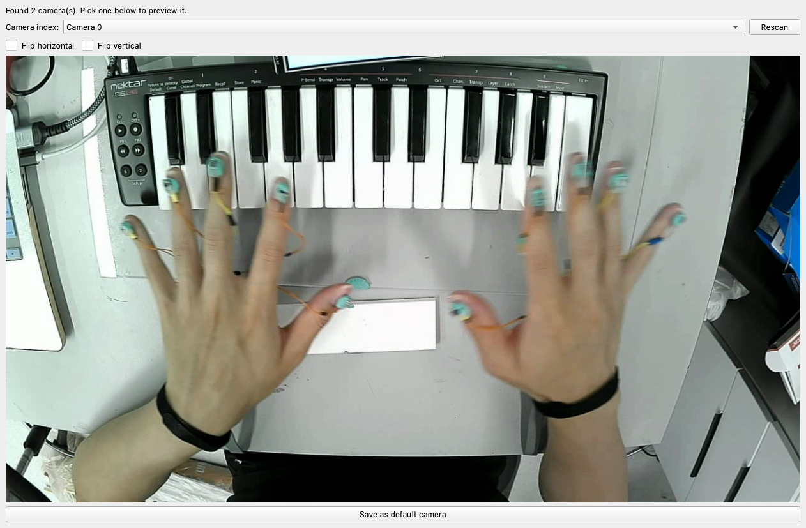
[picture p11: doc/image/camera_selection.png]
Camera Selection Wizard


Which camera the platform uses, and which way up its image is.

1. The window scans camera indices on open. Pick one from **Camera index** to
   preview it. **Rescan** re-runs the scan after plugging something in.
2. Tick **Flip horizontal** / **Flip vertical** until the preview matches
   what you see from above the keyboard. Get this right now — every profile
   you calibrate afterwards is a pixel mask of *this* orientation.
3. **Save as default camera** writes the index and both flips to
   `config.json`.

Standalone: `python setup_camera_wizard.py`

### 1.3 Keyboard Calibration Wizard

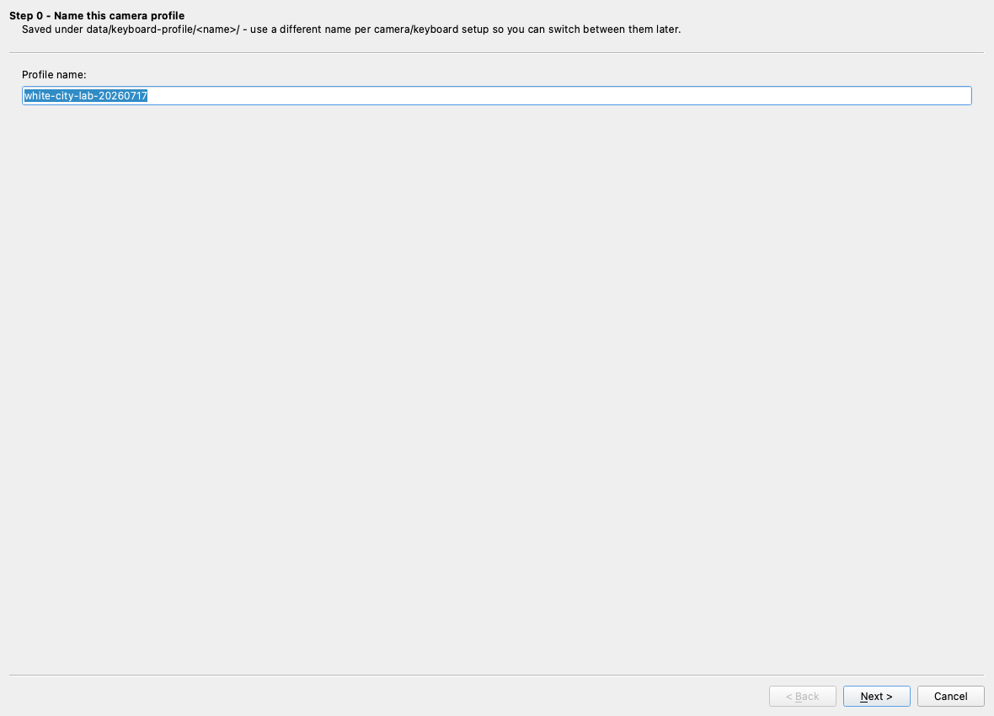
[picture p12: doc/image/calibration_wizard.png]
Keyboard Calibration Wizard — step 0


The first of the three FingerAccuracy pipeline stages: mark each piano key's
exact pixel range in the camera image and save it as a **profile**. The
wizard's own steps are numbered from 0 below.

**Step 0 — name the profile.** Saved under `data/keyboard-profile/<name>/`.
Use a different name per camera/keyboard setup so you can switch between them
later.

**Step 1 — capture a photo.** Point the camera at the keyboard and press
**Capture**. Everything after this works on that still frame, not on the live
feed.

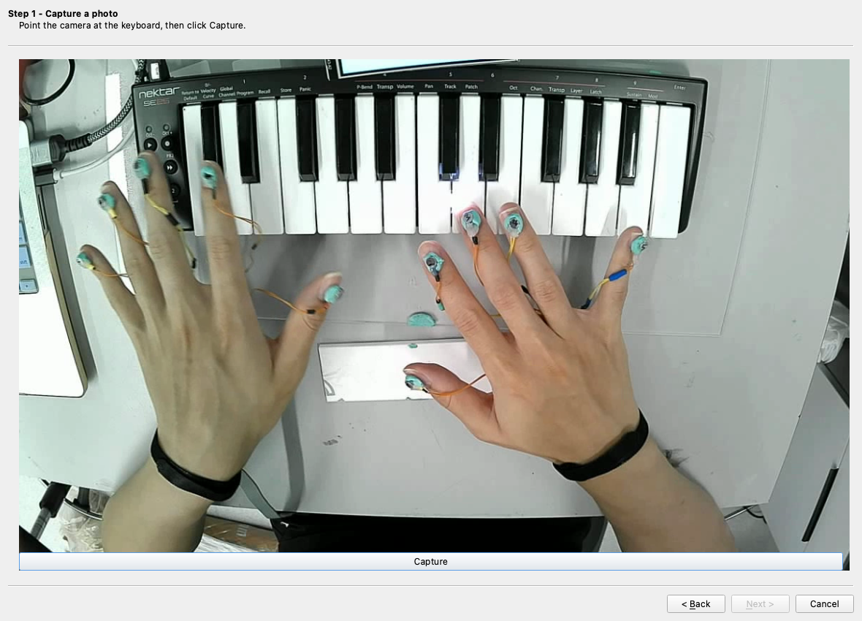
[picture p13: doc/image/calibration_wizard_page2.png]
Keyboard Calibration Wizard — Step 1, capture a photo


**Step 2 — mark the keyboard boundary.** Click the top-left corner of the
keyboard, then the bottom-right. **Reset points** starts the pair over.

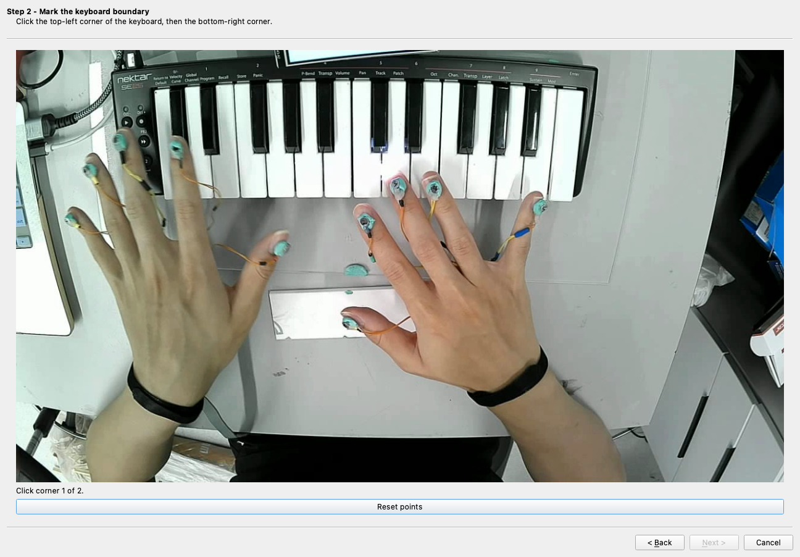
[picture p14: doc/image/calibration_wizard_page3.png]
Keyboard Calibration Wizard — Step 2, mark the boundary


**Remaining steps — fill each key.** You click inside each key and it is
filled paint-bucket style, bounded by Canny edges. The wizard is
mouse-and-buttons only, with no keyboard shortcuts. The result is
`keyboard_template.json` (key ids and white/black kind) plus
`keyboard_key_map.png`, a pixel map whose value at each pixel is that pixel's
key id plus one.

> A profile is only valid while the camera and the keyboard do not move
> relative to each other. Nudge the tripod and every key id shifts silently.
> If that happens, re-run this wizard.

Saving also sets `active_keyboard_profile` in `config.json` — the profile
every other tool uses by default.

Standalone: `python setup_keyboard_wizard.py`

### 1.4 MIDI Mapping Wizard

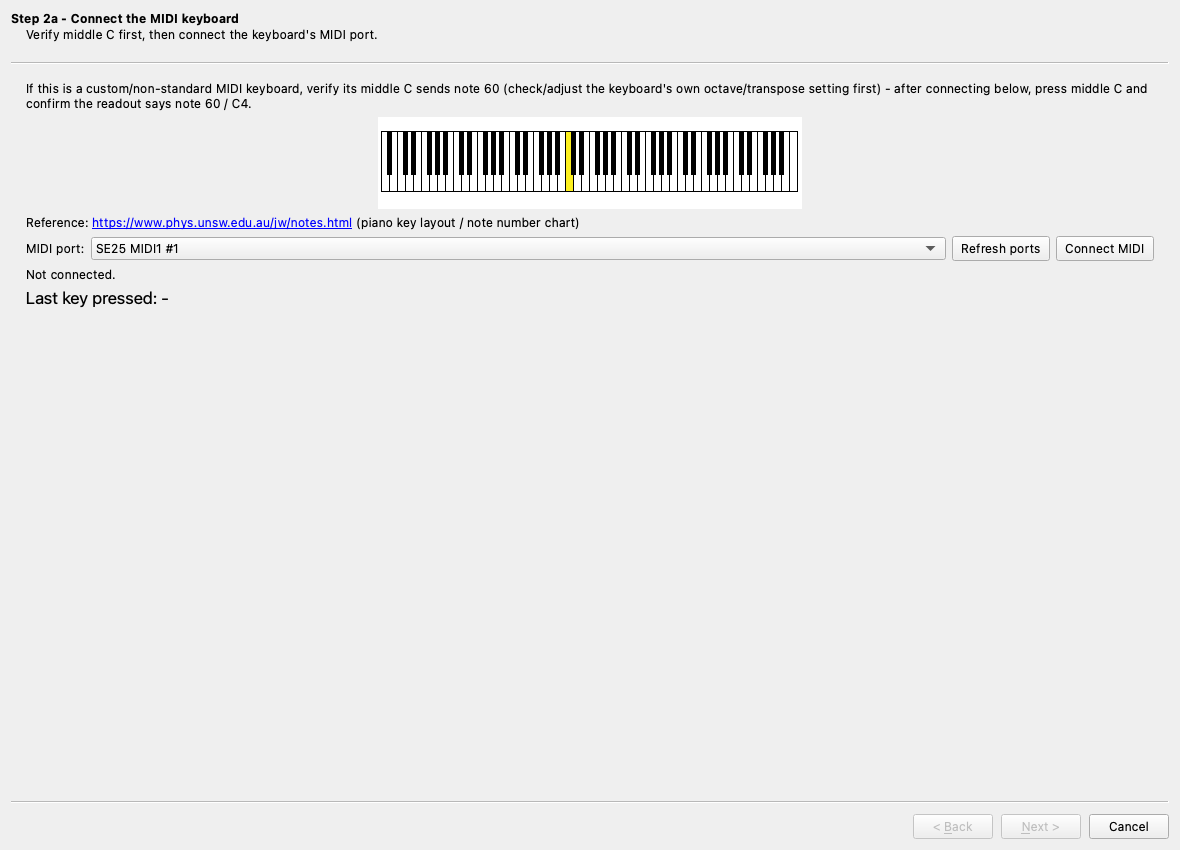
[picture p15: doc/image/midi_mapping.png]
MIDI Mapping Wizard


The second pipeline stage: teach the profile which MIDI note number each
calibrated key sends.

**Step 2a — pick the profile and the MIDI port.** Two keyboards of the same
model report the same port name; the pickers disambiguate them as
`SE25 MIDI1 #1` and `SE25 MIDI1 #2`, numbered in the order this machine
enumerated them. That numbering is not a device identity — it can change when
something is replugged.

**Step 2b — press the highlighted key on the physical keyboard, in order.**
The next key to map is highlighted yellow on the calibrated image and the
counter underneath reads `n/25 keys mapped`. Whatever note number the key
actually sends is what gets recorded.

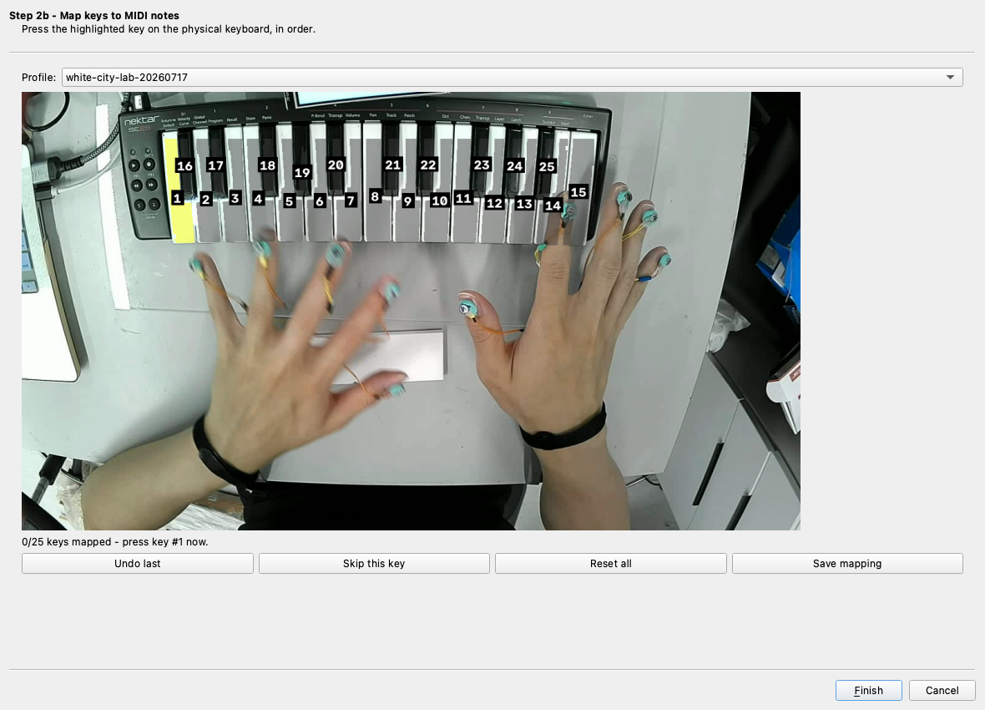
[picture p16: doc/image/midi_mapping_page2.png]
MIDI Mapping Wizard — pressing the highlighted key


| Button | Use it when |
|---|---|
| **Undo last** | The wrong key was pressed |
| **Skip this key** | That key is not wired, or you do not want it mapped |
| **Reset all** | Start the whole mapping over |
| **Save mapping** | Write `midi_mapping.json` next to the template |

> Can't tell two identical keyboards apart? `python test-script/MIDI.py`
> listens on every port at once and prints which label your key press arrived
> on. On macOS, renaming the instruments in **Audio MIDI Setup → MIDI
> Studio** makes the raw names differ and the `#n` suffixes disappear.

Standalone: `python setup_midi_mapping_wizard.py`

### 1.5 Keyboard Profile Selection, Region Preview

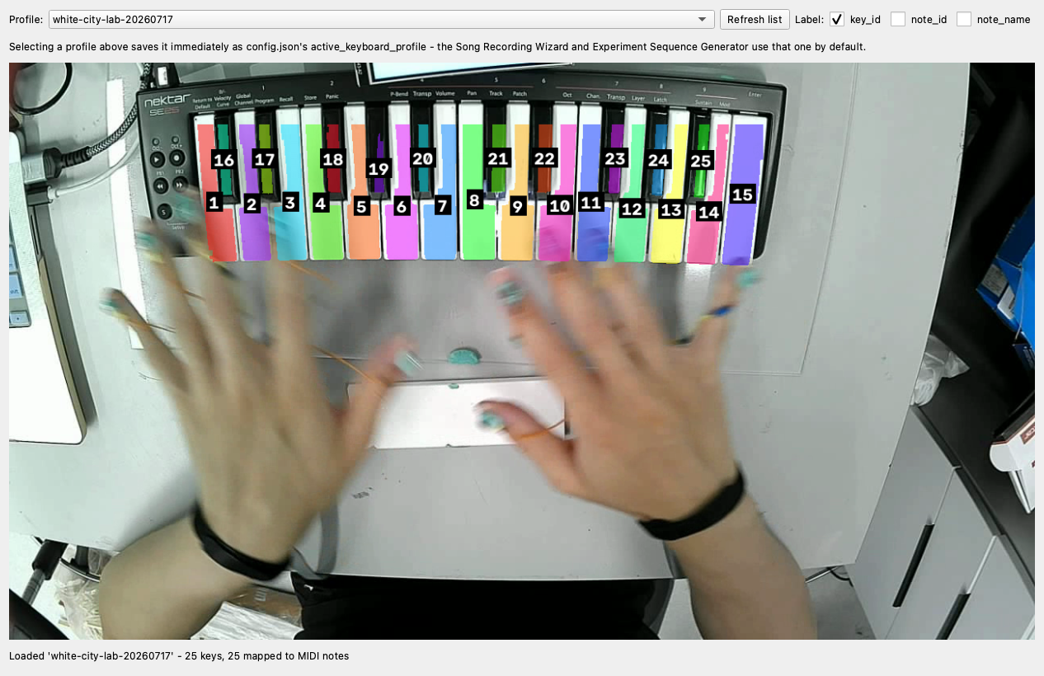
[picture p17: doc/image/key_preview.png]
Keyboard profile preview


Pick a saved profile from the dropdown and see its key masks drawn on the
live camera feed, with the key id (or the MIDI note name) on each key. No
detection runs here — it just redraws the selected profile's key map every
frame.

This is the sanity check to run whenever you suspect the camera has moved:
if the coloured masks no longer sit on the physical keys, the profile is
stale and the calibration wizard needs re-running.

Standalone: `python test_keyboard_preview.py`

### 1.6 Visual Guidance Cue Selection

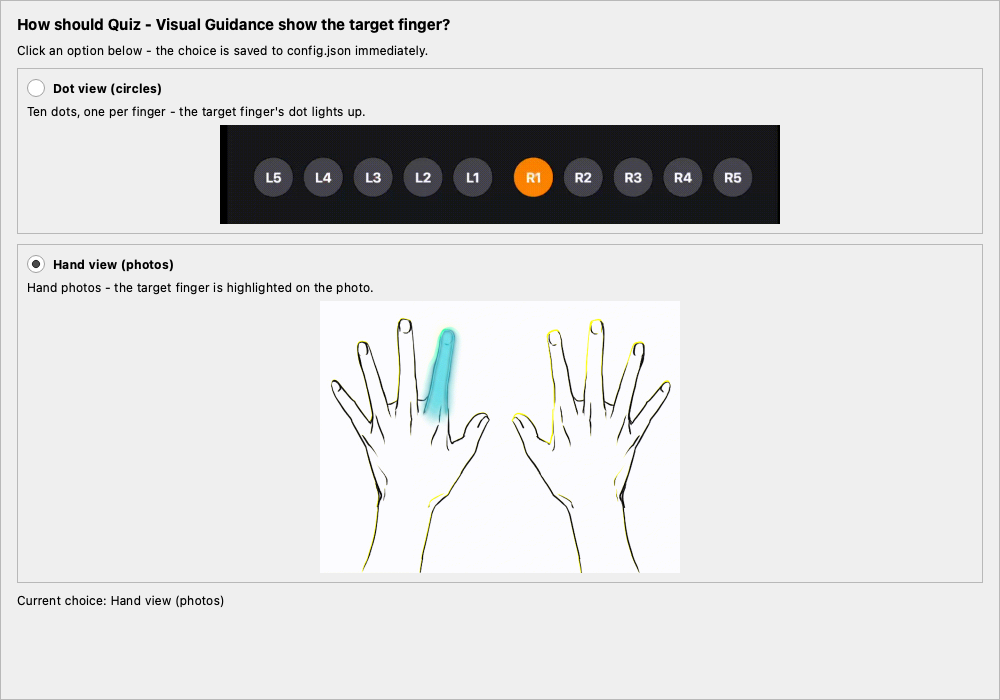
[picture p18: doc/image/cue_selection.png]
Visual Guidance Cue Selection


The visual finger cue can be shown as ten **dots** or as highlighted **hand**
photos. This window is the one place that choice is made: it plays both demo
animations stacked vertically, and clicking either the animation or its radio
button saves that style straight into `config.json`
(`visual_cue_style`).

The quiz then reads the stored value on launch rather than asking every time,
which is why this lives in Initial Setup alongside the other run-once
wizards.

### 1.7 Haptic Actuator Defaults

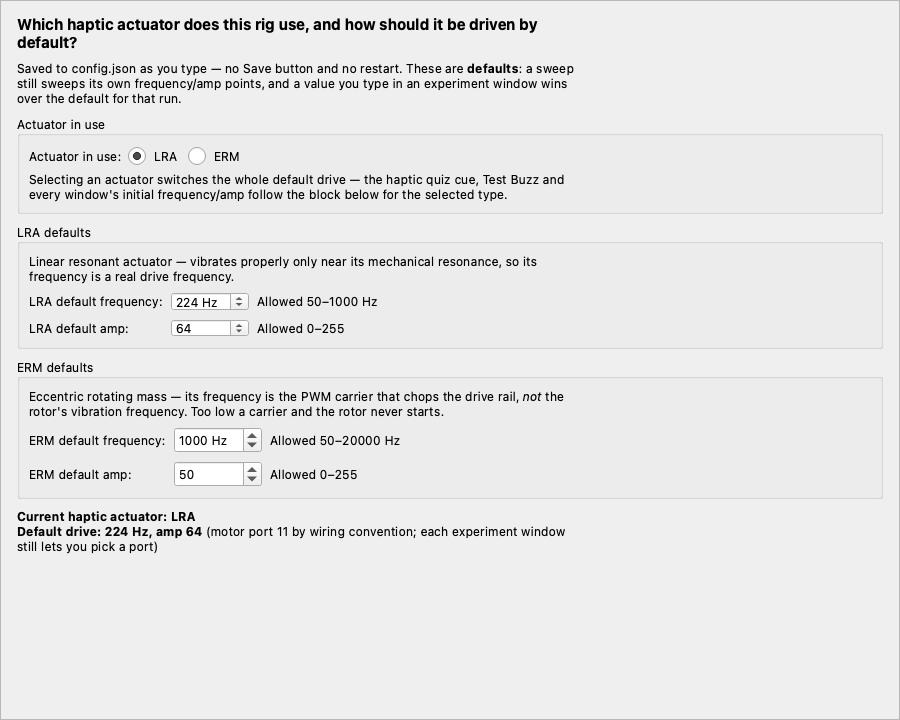
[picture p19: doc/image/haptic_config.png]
Haptic Actuator Defaults


Which vibration actuator the rig drives — and how hard — is **one setting for
the whole project**. No script, window or experiment carries its own copy.

- **Actuator in use**: LRA or ERM. Selecting one switches the whole default
  drive: the haptic quiz cue, Test Buzz, and every window's initial
  frequency/amp follow the block for the selected type.
- **LRA defaults**: frequency 50–1000 Hz, amp 0–255. An LRA's frequency is a
  *real mechanical drive frequency* — it only vibrates properly at or very
  near its resonance, which is what the section 10 sweeps measure.
- **ERM defaults**: frequency 50–20000 Hz, amp 0–255. An ERM's frequency is
  the **PWM carrier** that chops the drive rail, *not* the rotor's vibration
  frequency. Too low a carrier and the rotor never starts.

Changes save to `config.json` as you type — there is no Save button and no
restart. These are **defaults**: a sweep still sweeps its own frequency/amp
points, and a value you type into an experiment window wins for that run.

---

## 2. Feature Testing

Prove each piece of the rig works on its own, before you rely on it in a
session. Nothing here writes experiment data.

### 2.1 Live Finger Detection

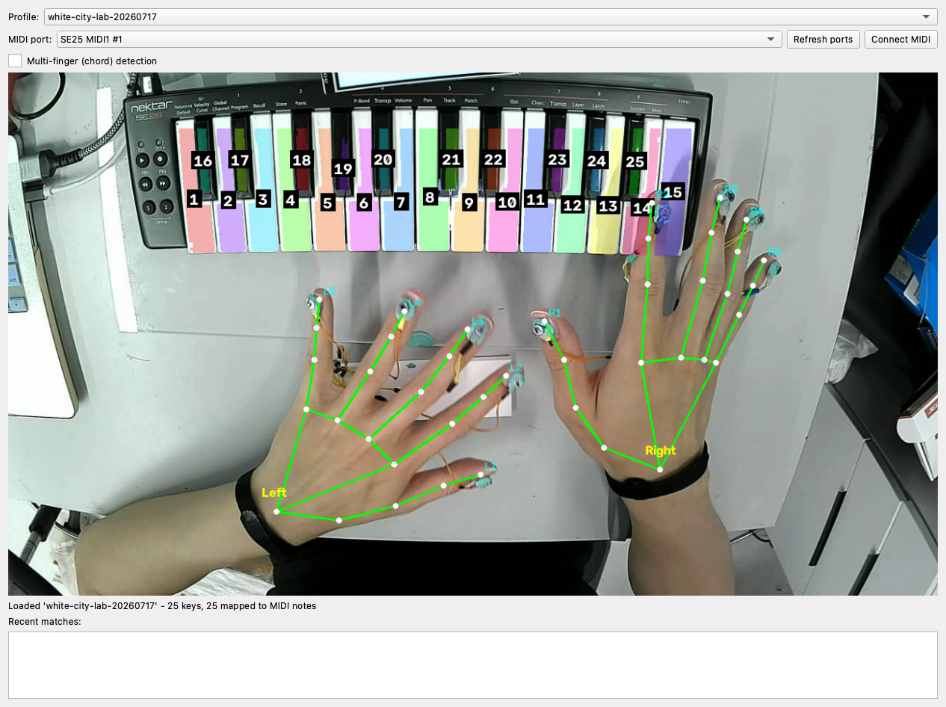
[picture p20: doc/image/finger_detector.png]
Live Finger Detection


The full FingerAccuracy pipeline running live: the calibrated key masks and
key ids drawn over the camera image, MediaPipe's hand skeleton with each
fingertip labelled `L1`–`L5` (left thumb → pinky) and `R1`–`R5` (right thumb
→ pinky), and real-time matching of every MIDI note-on to the fingertip that
pressed it.

1. Pick the **Profile**.
2. Pick the **MIDI port** and press **Connect MIDI** (**Refresh ports** if
   you plugged in after opening the window).
3. Play. Each note-on appears in **Recent matches** as the key it hit and the
   finger that hit it.

**Multi-finger (chord) detection** changes what happens when several notes
fire in the same instant: with it on, they are matched together so no two
notes can be credited to the same fingertip.

Works with zero, one or two hands in frame. This is the quickest way to
confirm a profile is still aligned and the finger judgement is sane.

Standalone: `python test_finger_accuracy.py`

### 2.2 Virtual Piano + LED Test

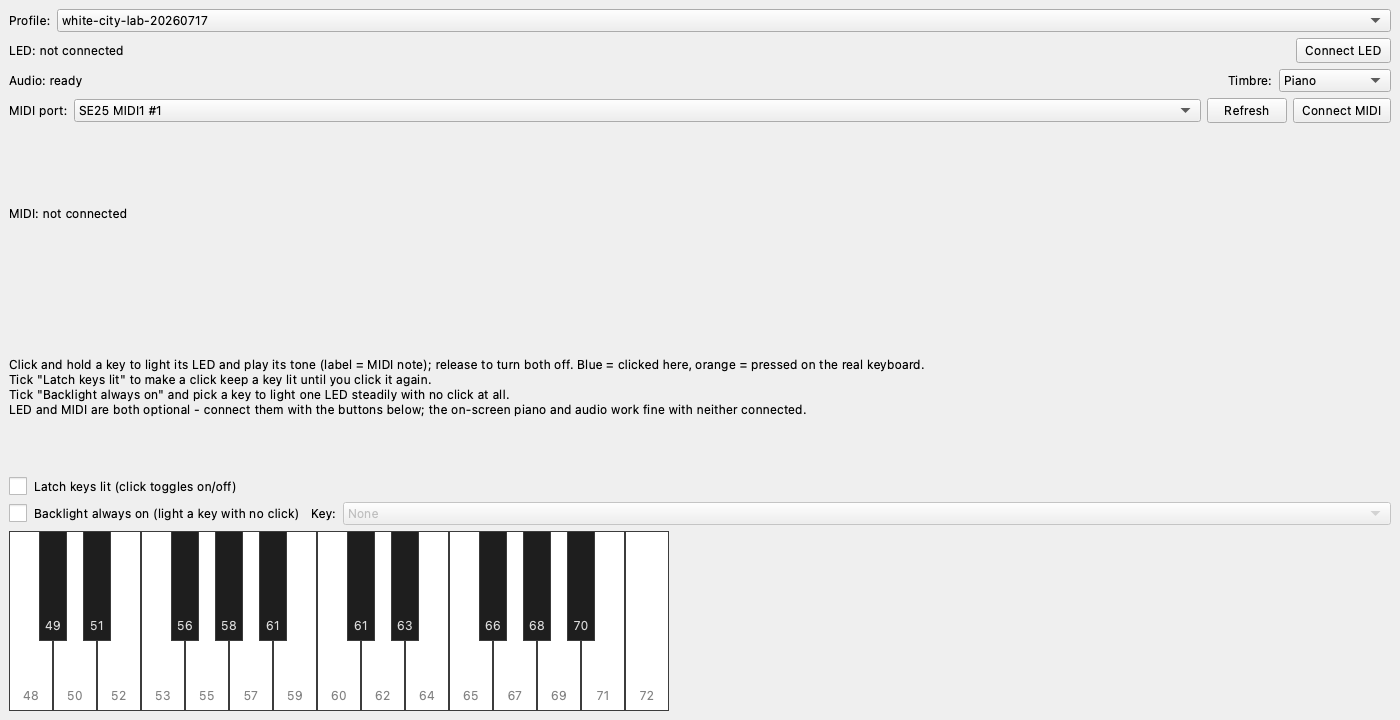
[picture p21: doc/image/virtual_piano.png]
Virtual Piano + LED Test


An on-screen piano that mirrors the calibrated profile, for checking the
physical LED strips without reading code.

- **Click and hold** a key → the matching LED(s) on the real strips light up
  and the tone plays; release and both stop. Blue = clicked here, orange =
  pressed on the real keyboard.
- **Latch keys lit** makes a click keep a key lit until you click it again.
- **Backlight always on** plus a **Key** selection lights one LED steadily
  with no click at all — this is what Demo Mode uses to photograph the
  backlight.
- **Connect LED** and **Connect MIDI** are deliberately manual buttons, not
  auto-connect: the window is meant to run against a second rig with no LED
  strip wired at all, so the on-screen piano, the audio and MIDI-driven
  highlighting all keep working with nothing attached.

Standalone: `python test_virtual_piano_led.py`

### 2.3 Haptic Vibrator Test

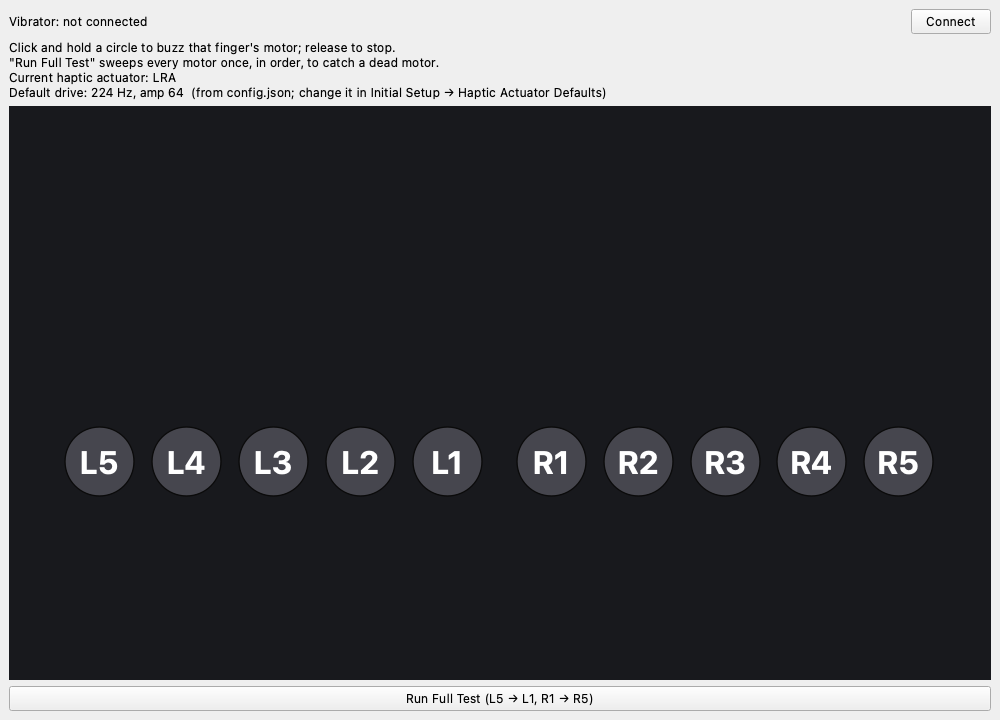
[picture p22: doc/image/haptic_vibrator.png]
Haptic Vibrator Test


Press **Connect** (top right), then click and hold a labelled circle — `L5`…`L1`,
`R1`…`R5`, the same layout as the haptic quiz's finger cue — to buzz that
finger's motor; release to stop it. **Run Full Test** sweeps every motor once,
`L5 → L1, R1 → R5`, so a dead motor is caught without ten separate clicks.

The header states which actuator is in use and at what drive, so you can see
at a glance that you are feeling the same cue the experiment delivers.

This exercises the *exact same* finger→motor mapping and the *exact same*
drive strength the haptic guidance condition uses: the mapping comes from
`app/haptic_cue.py` and the amp/frequency from `config.json`'s haptic block.
Change the strength in [Haptic Actuator Defaults](#17-haptic-actuator-defaults),
not here.

Standalone: `python test_haptic_vibrator.py`

### 2.4 Haptic Motor Bench

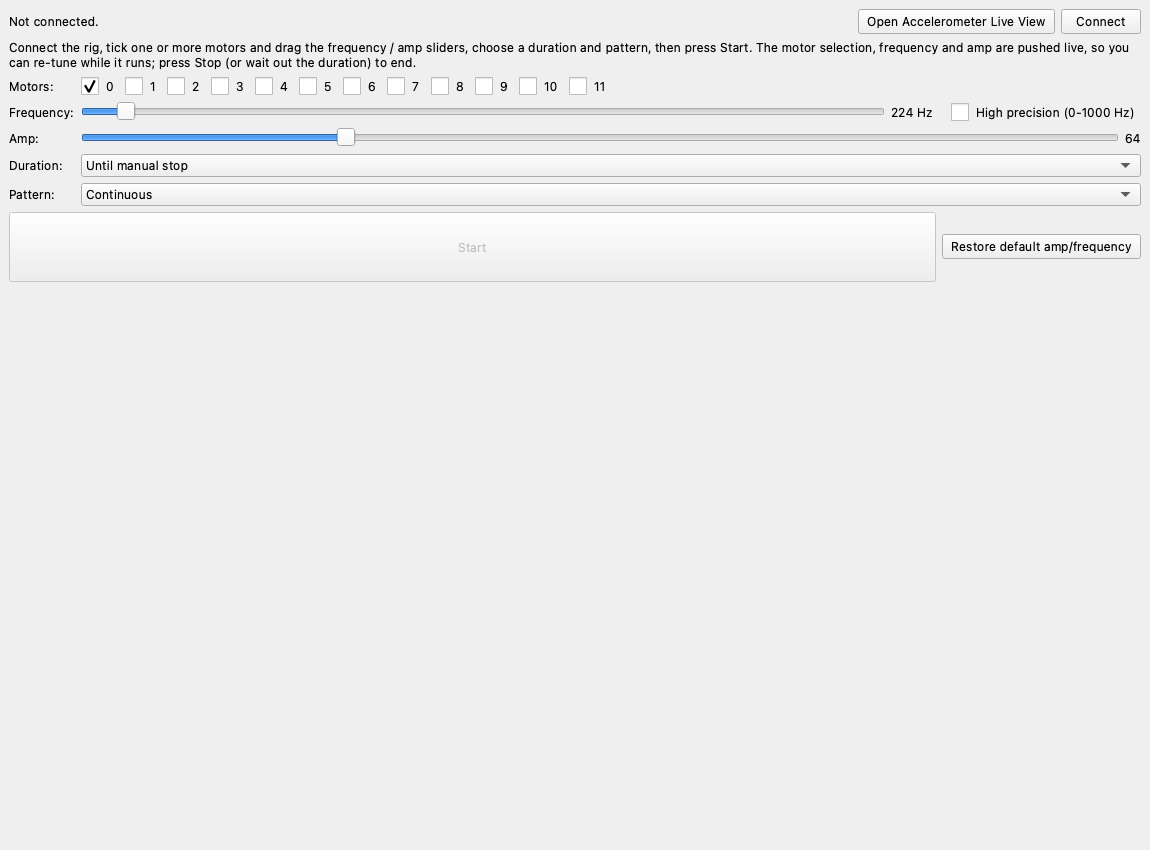
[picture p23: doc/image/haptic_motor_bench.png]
Haptic Motor Bench


A bench for *feeling* one or several actuators at an arbitrary drive, without
editing a script or running a full sweep — e.g. trying the LRA at its
resonance against the ERM at a kHz carrier, or sanity-checking a wiring
change.

1. Tick one or more **motor ports**.
2. Drag the **frequency** and **amp** sliders. They open on the configured
   default drive for the actuator in use.
3. Choose a **run duration** and a **vibration pattern**, then Start.

Selection, frequency and amp are pushed to the device **live**: while motors
are energised, dragging a slider or ticking a port re-tunes the running set
immediately, so you feel the change without stopping. On disconnect or exit
every retuned port's frequency is reset to the boot default.

Standalone: `python test_haptic_single_motor.py`

### 2.5 Accelerometer Live View

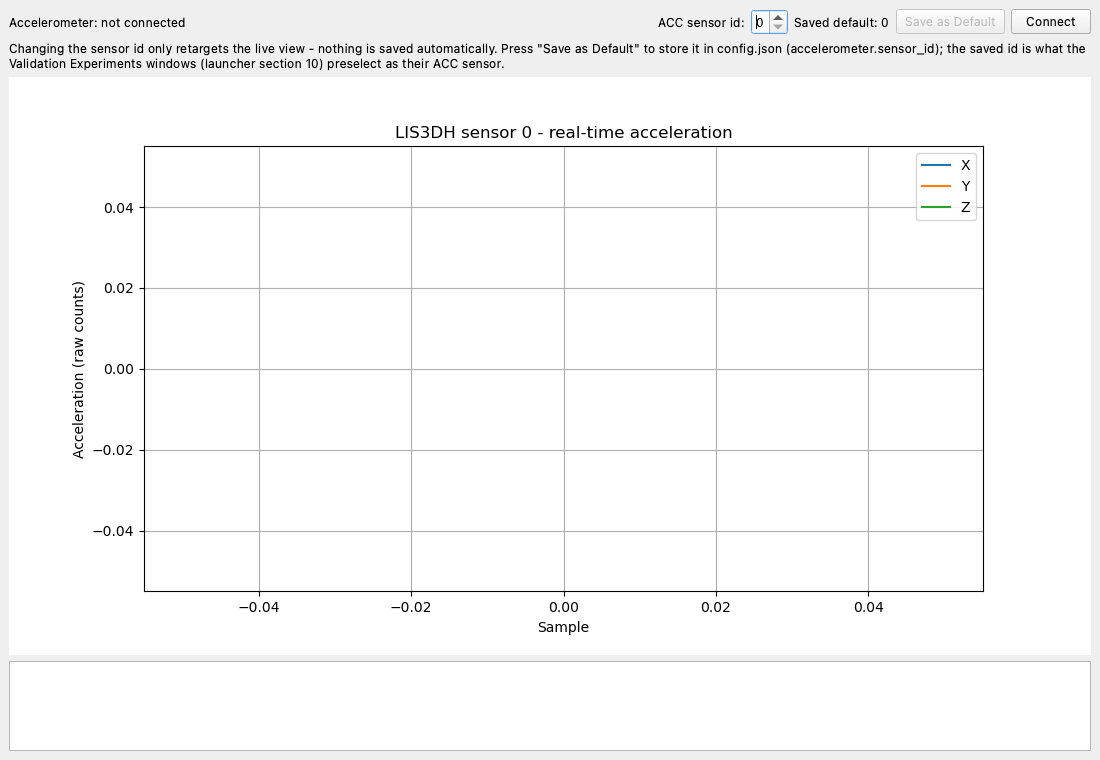
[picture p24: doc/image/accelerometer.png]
Accelerometer Live View


A live X/Y/Z plot of one LIS3DH on the vibration rig, at 100 Hz. Press
**Connect** and the log underneath reports the port it auto-detected, the
firmware identity it handshook with, and the stream starting.

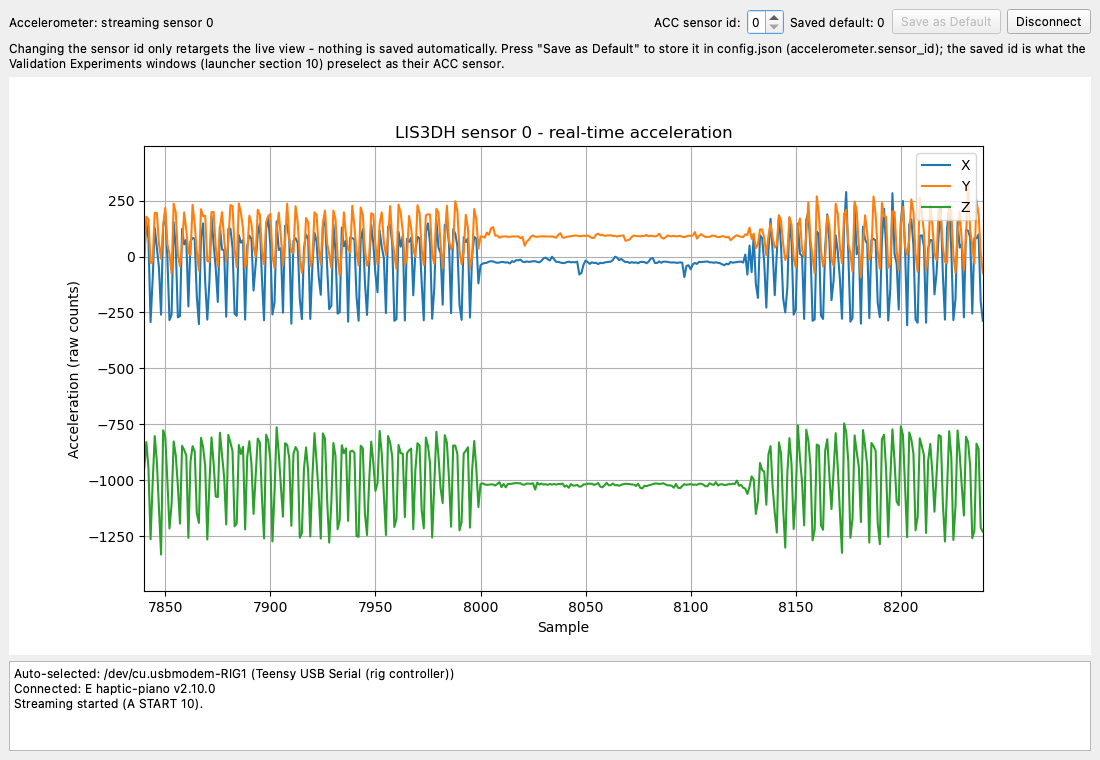
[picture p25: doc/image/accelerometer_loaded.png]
Accelerometer Live View — streaming


Reading the trace: **Z rests near −1000 counts** because that axis carries
gravity, and the bursts are the actuator driving at the configured default
(224 Hz, amp 64) with the quiet stretch between them the noise floor. That
contrast is what the window is for — if a burst does not stand clear of the
floor, the sensor is not coupled to the motor and every measurement in
section 10 would be worthless.

The stream carries every sensor interleaved, so the **sensor id** selector
switches which one you are watching live, with no restart.

Changing the selector only retargets the view. Nothing is written until you
press **Save as Default**, which stores the id in `config.json`
(`accelerometer.sensor_id`) — the sensor the section 10 sweep windows
preselect. The currently saved id is shown next to the selector so the two
states cannot be confused.

---

## 3. Recording & Playback

### 3.1 Song Recording Wizard

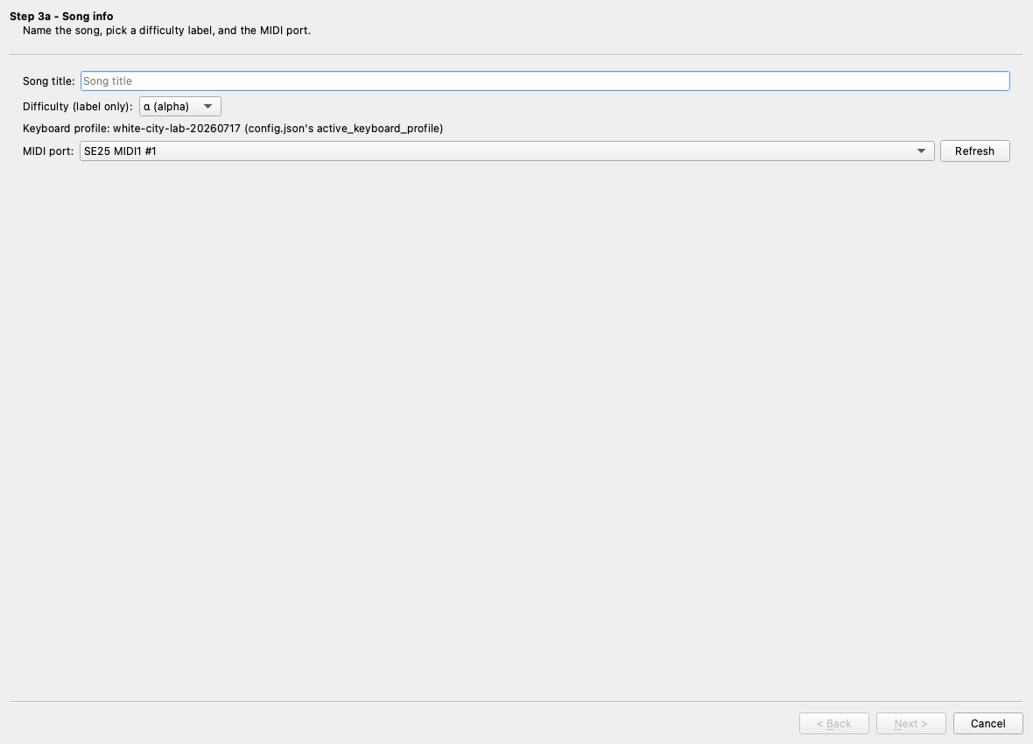
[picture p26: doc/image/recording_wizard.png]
Song Recording Wizard


A teacher plays a song once; the wizard records the video and the MIDI
together, flashes the LEDs for sync, and saves a fingering-annotated score
under `data/music/<song>/`.

**Step 3a — song info.** Name the song, pick a difficulty label (a label
only — it does not change anything the wizard does) and choose the MIDI port.
The keyboard profile is not a choice here: it is always `config.json`'s
`active_keyboard_profile`, shown so you can confirm it.

**Step 3b — record.** Watch the camera preview, play the song, stop when
done. Video and MIDI are captured together and the LEDs flash once so the two
can be aligned afterwards.

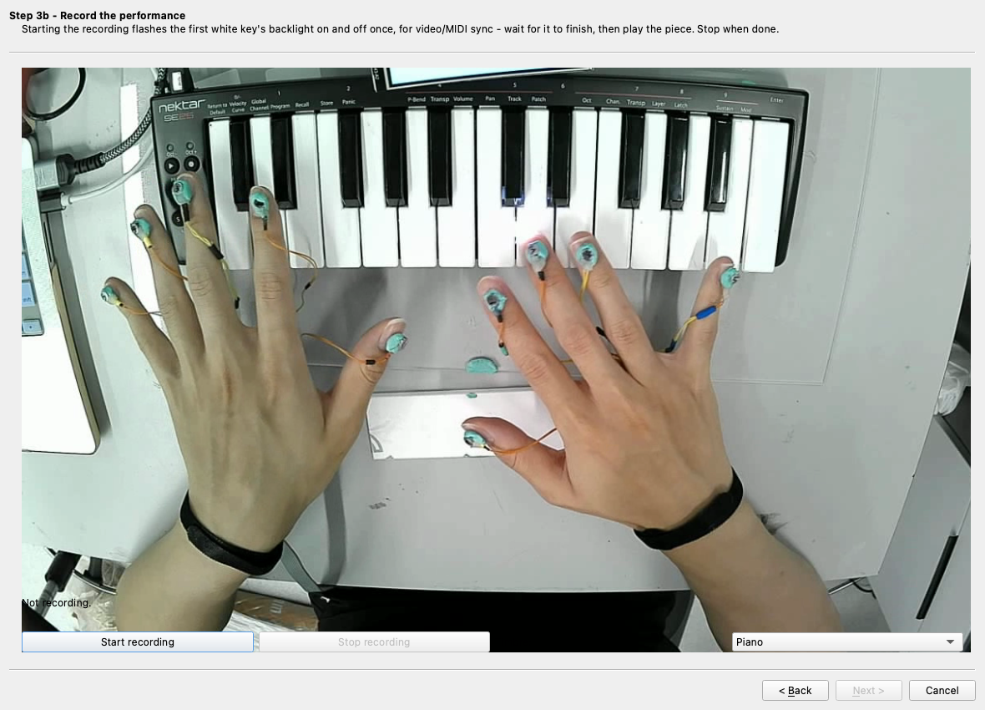
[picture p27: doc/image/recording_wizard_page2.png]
Song Recording Wizard — recording


**Step 3c — review & save.** **Compute fingering & save** runs the detection
over the recording so every note carries the finger that played it
(`fingering.json`), then writes the song. That fingering is what the quizzes
cue against.

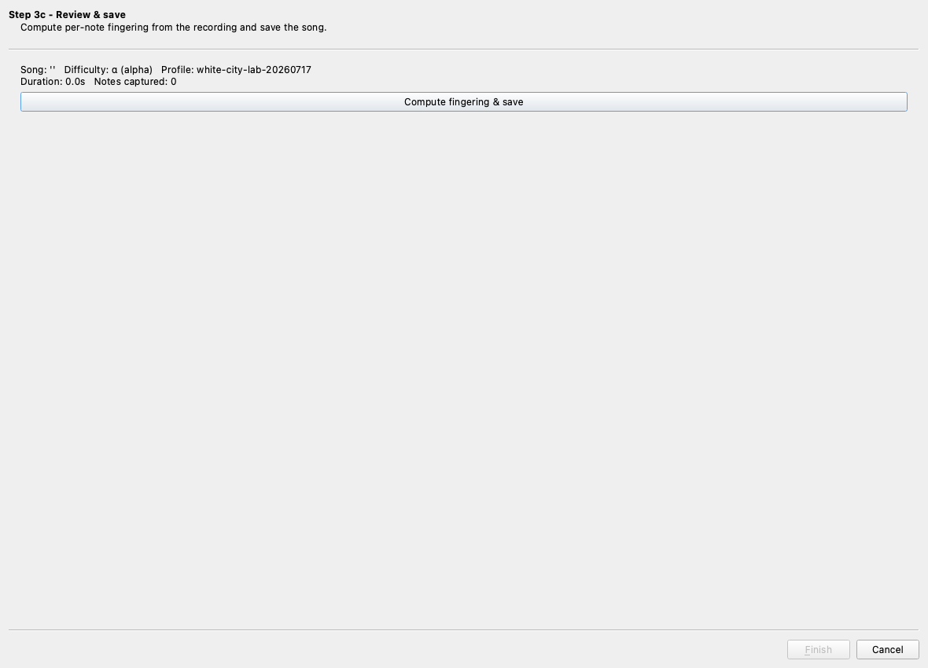
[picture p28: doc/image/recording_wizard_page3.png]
Song Recording Wizard — review and save


Standalone: `python music_recording_wizard.py`

### 3.2 Song Playback

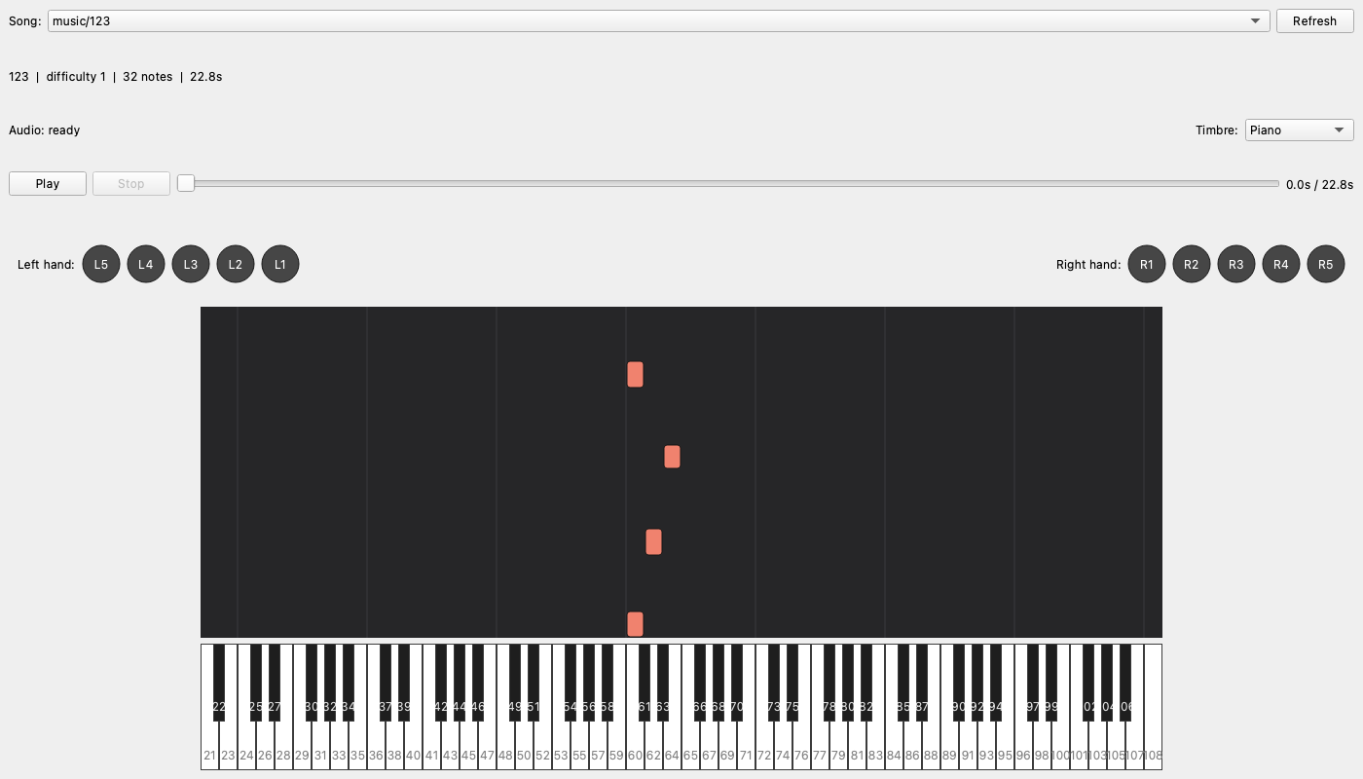
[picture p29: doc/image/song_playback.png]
Song Playback


Replays a saved song on an on-screen **88-key** piano, highlighting each key
as it is pressed and lighting a dot for whichever finger (`L1`–`L5` /
`R1`–`R5`) played it.

No camera, MIDI device or LED strip is needed — this only reads back files
that are already saved. The keyboard is a full A0–C8 piano rather than the
~25 keys the recording keyboard physically has, because this is a pure
display.

Standalone: `python music_playback.py`

---

## 4. Experiment Sequence Design

The stimuli for the Main User Study. The algorithm — the difficulty
components, the hand regions, the matching tolerances — is written up in
[`doc/SEQUENCE_GENERATOR_ALGORITHM.md`](SEQUENCE_GENERATOR_ALGORITHM.md); this
section is only how to drive the windows.

### 4.1 Experiment Sequence Generator

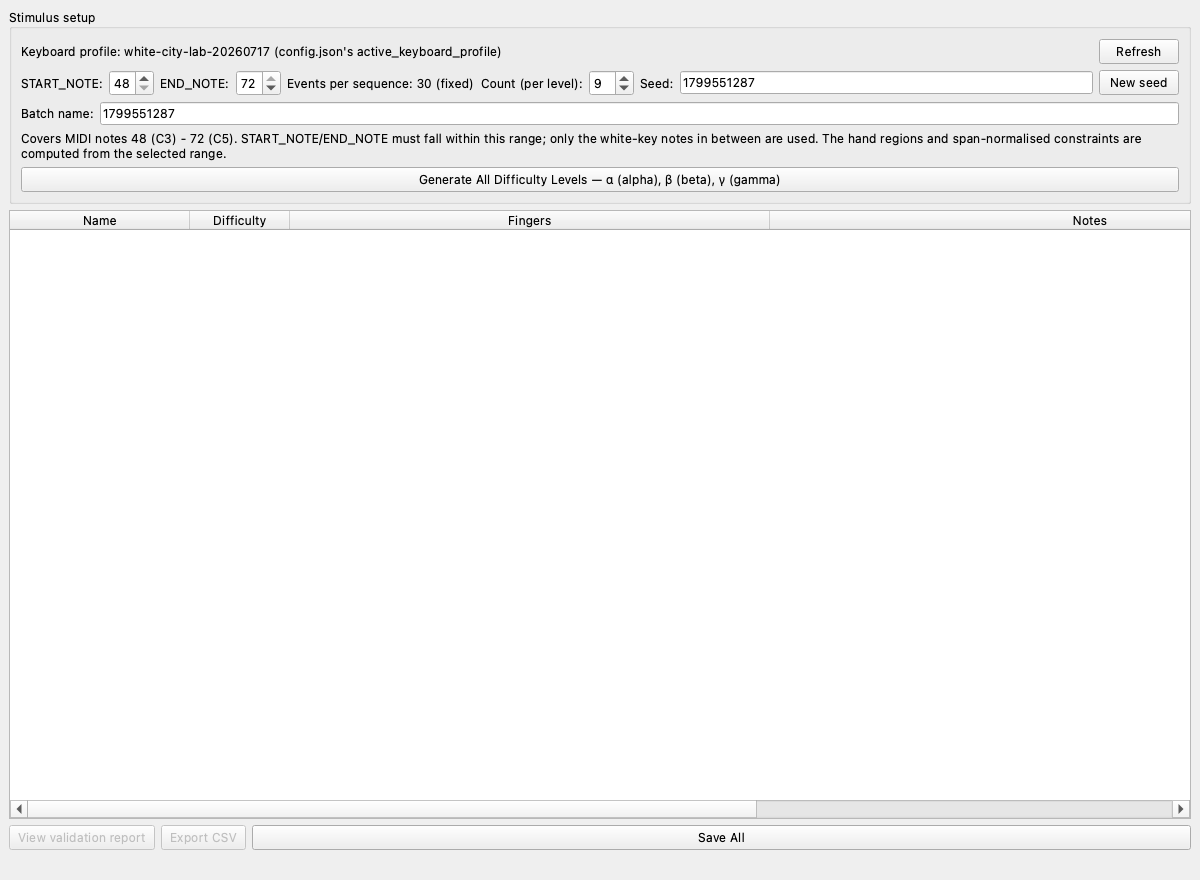
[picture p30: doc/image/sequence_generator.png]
Experiment Sequence Generator


Builds a matched family of 30-event bimanual sequences for **every**
difficulty level at once — α (alpha), β (beta), γ (gamma). There is no level
picker, because a stimulus set always needs all three.

1. Check the header: the keyboard profile is always `config.json`'s
   `active_keyboard_profile`, so a sequence can never be generated against
   the wrong physical keyboard.
2. Set **START_NOTE** / **END_NOTE**. These are real MIDI note numbers,
   bounded by what that profile's `midi_mapping.json` actually covers; only
   the white-key notes in between are used. Hand regions and the
   span-normalised constraints are computed from the range you choose.
3. Set **Count (per level)** — the family size, default 9. Every sequence in a
   level's family is named `<level symbol>-<id>`, e.g. `α-1`…`α-9`.
4. Set the **Seed** (or press **New seed**) and a **Batch name**. The seed is
   what makes a batch reproducible.
5. **Generate All Difficulty Levels**.

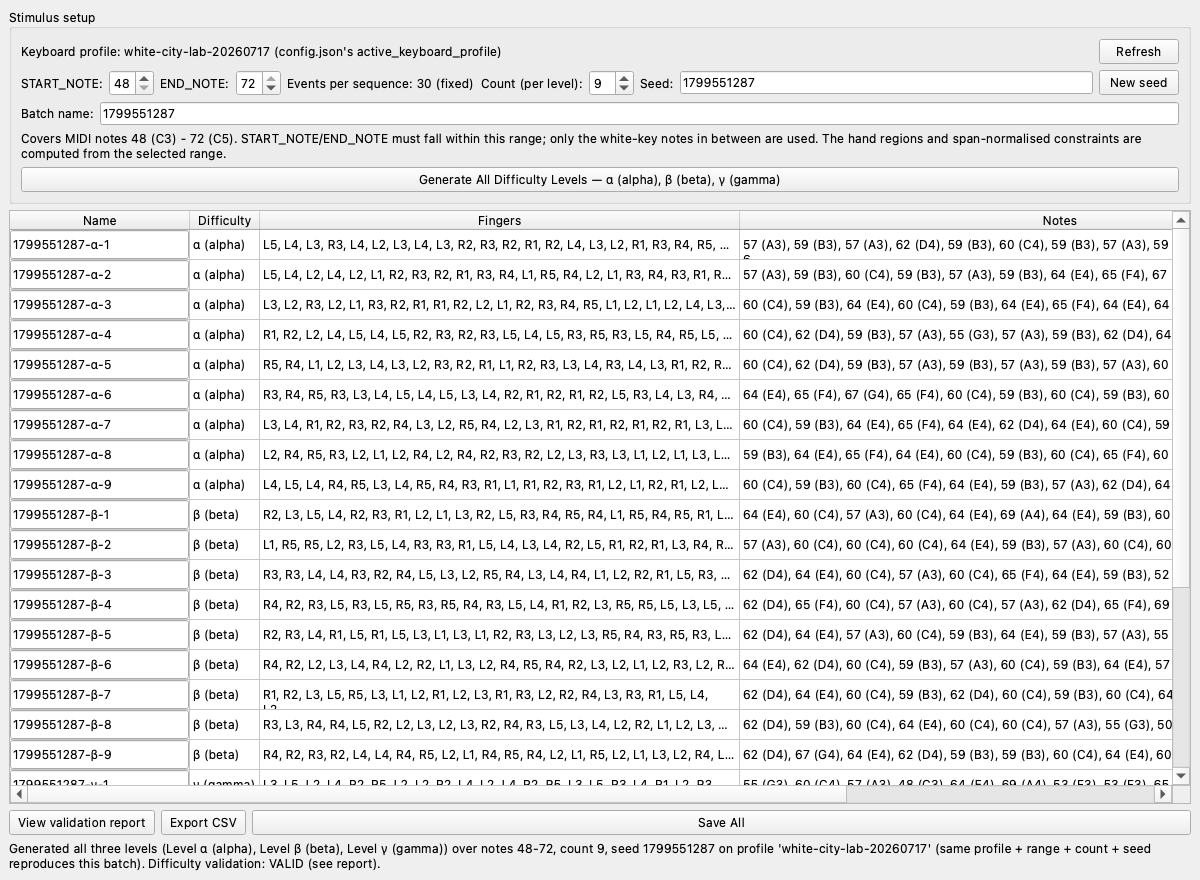
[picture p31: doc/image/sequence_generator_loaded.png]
Experiment Sequence Generator — generated batch


One row per generated sequence: its name, difficulty level, the fingering and
the notes, with the family-matching statistics further right (the table scrolls
horizontally). The status line underneath restates exactly what would reproduce
the batch — same profile, range, count and seed — and the verdict of the
difficulty validation, which runs automatically after every generation.

**View validation report** opens that validation in full, **Export CSV** writes
the table, and **Save All** writes the batch to `data/sequence/<batch>/`.

Standalone: `python experiment_sequence_wizard.py`

### 4.2 Sequence/Music Metrics

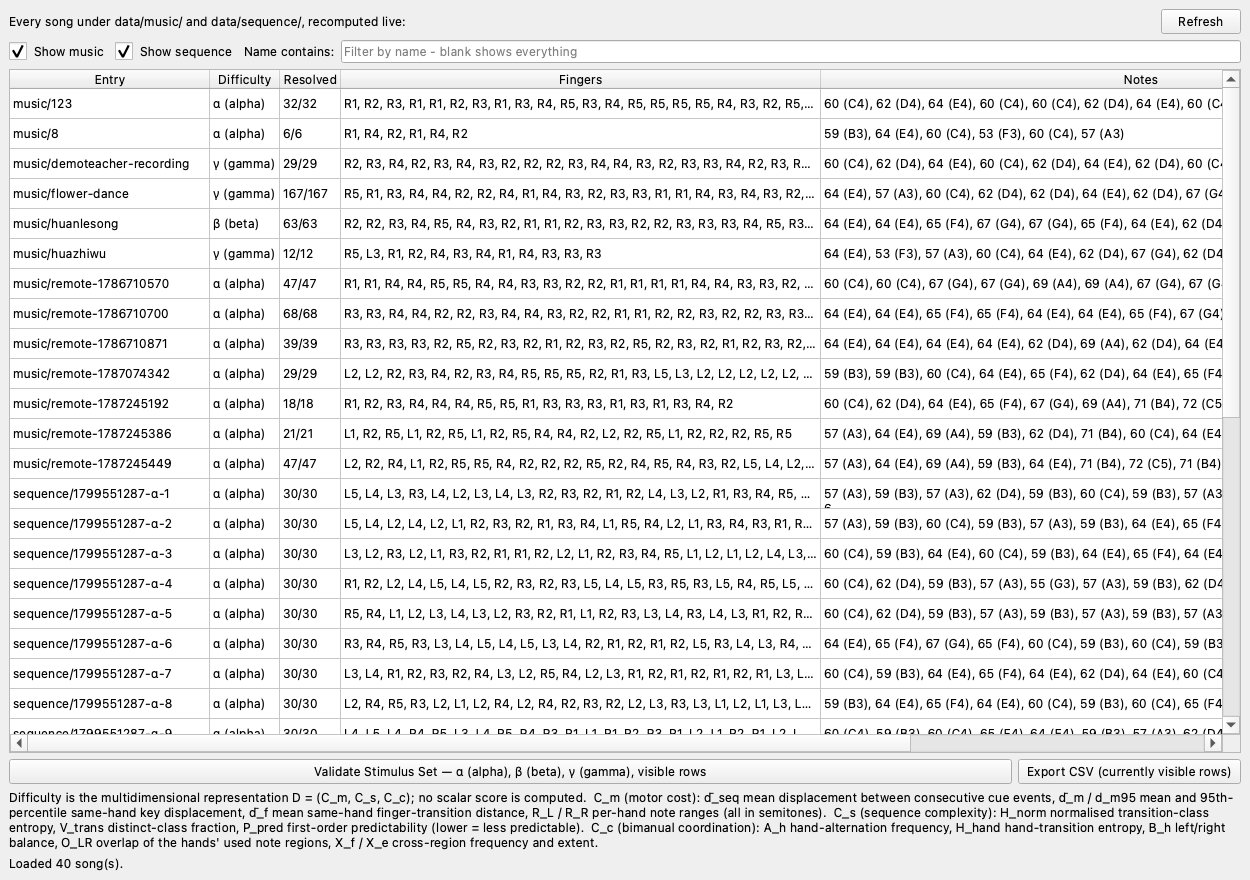
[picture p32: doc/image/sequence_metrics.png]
Sequence / Music Metrics


A read-only viewer over what is already saved: **every** song under
`data/music/` and every sequence under `data/sequence/`, in one table,
recomputed live by the exact same functions the generator uses. Use it to
compare one batch against another, or a recorded song against the generated
families.

**Show music** / **Show sequence** and the **Name contains** filter narrow the
list. The **Resolved** column is how many of that entry's events have a
resolved fingering. The legend underneath spells out the difficulty
representation the columns come from, and **Validate Stimulus Set** re-runs the
difficulty validation over whichever rows are currently visible.
**Export CSV** writes those same visible rows.

### 4.3 Single Song Complexity Evaluation

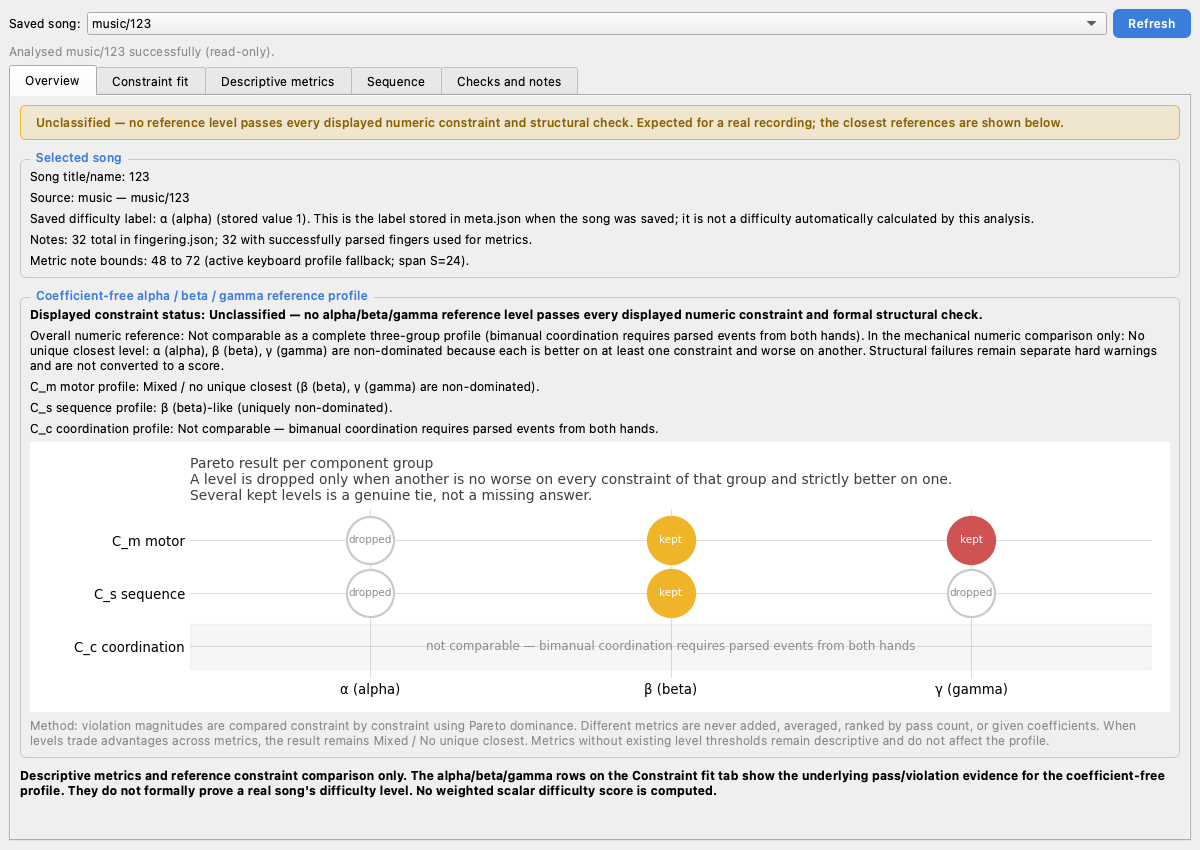
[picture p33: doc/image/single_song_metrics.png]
Single Song Complexity Evaluation


The same measures for **one** saved song, laid out over five tabs:

| Tab | Shows | |
|---|---|---|
| Overview | The headline complexity figures for this song | [screenshot](image/single_song_metrics_tab1-overview.png) |
| Constraint fit | How the song sits against the generator's reference constraints | [screenshot](image/single_song_metrics_tab2-constraint-fit.png) |
| Descriptive metrics | The component-by-component breakdown | [screenshot](image/single_song_metrics_tab3-descriptive-metrics.png) |
| Sequence | The note/finger sequence itself | [screenshot](image/single_song_metrics_tab4-sequence.png) |
| Checks and notes | What was and was not verifiable for this song | [screenshot](image/single_song_metrics_tab5-checks-and-notes.png) |

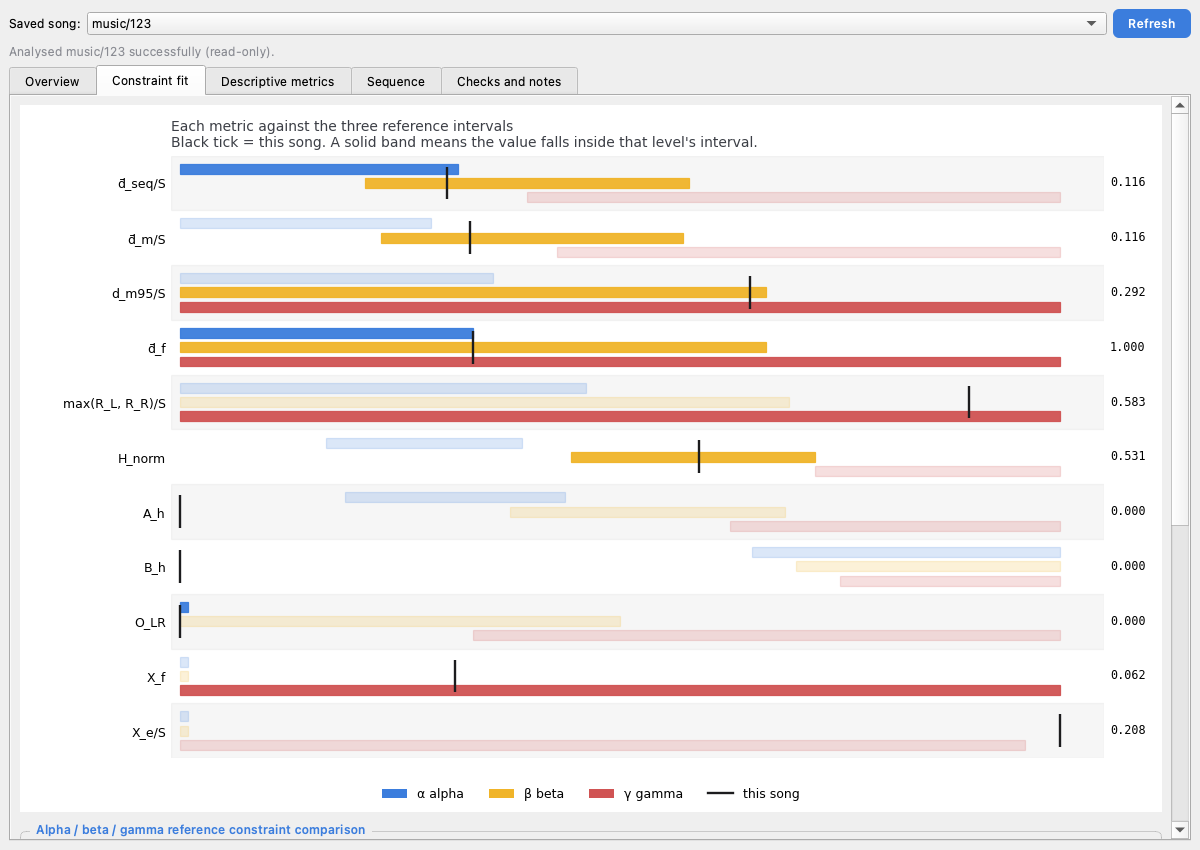
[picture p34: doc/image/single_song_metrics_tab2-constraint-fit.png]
Single Song Complexity Evaluation — constraint fit


---

## 5. Practice & Assessment

One cue-response quiz over a saved song or generated sequence. The two
buttons open the *same* window with a different finger cue — everything else
(LED key cueing, the timeout countdown, the recording, the analysis) is
identical.

### 5.1 Quiz — Visual Guidance

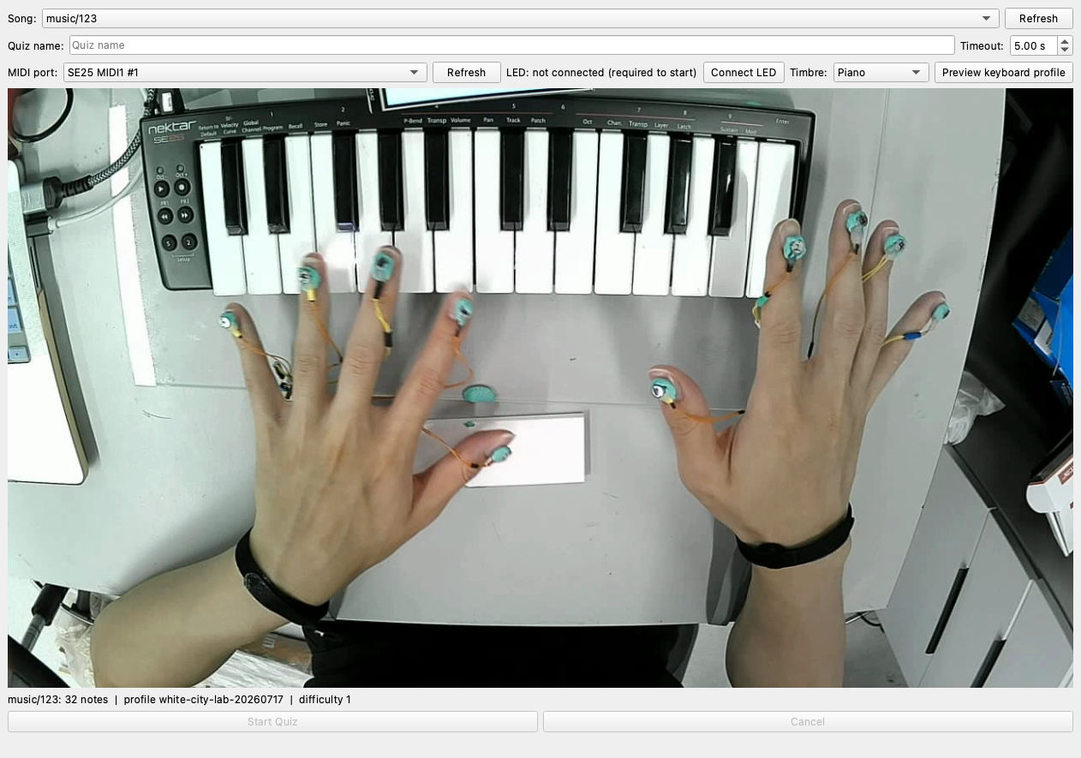
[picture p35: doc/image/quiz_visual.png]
Quiz — Visual Guidance


1. Pick the **Song** (a recorded song or a generated sequence) and give this
   attempt a **Quiz name**.
2. Pick the **MIDI port**, the **Timbre** and the **Timeout** per event.
3. Press **Connect LED** — a connected strip is required to start.
4. Press **Preview keyboard profile** to confirm the camera still matches the
   calibration. It draws the active profile's key masks and ids over the
   frame already on screen; nothing is saved, and the button is disabled
   while recording.
5. **Start Quiz**.

Per event: the target key's LED lights and the cue window says which finger
to use. The cue window is a separate window — drag it to the participant's
display and fullscreen it.

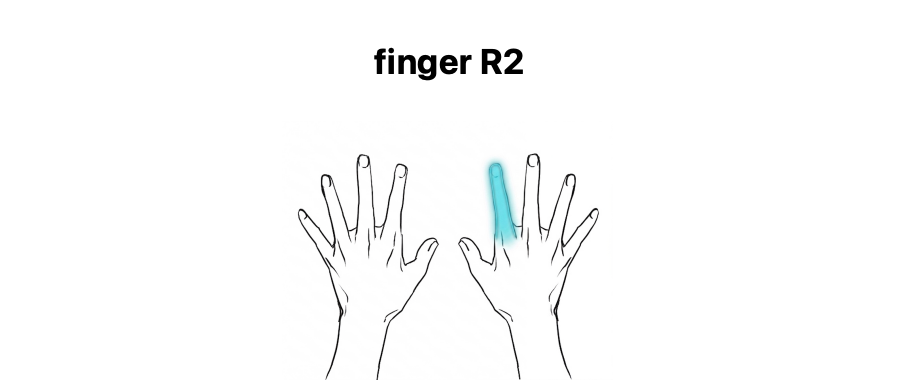
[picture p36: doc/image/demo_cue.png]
The visual finger cue screen


The whole session's video and MIDI are recorded to `data/quiz/<quiz name>/raw/`
throughout, and afterwards the finger detection is run once over the
recording. The results — key accuracy, timing error, finger accuracy and a
per-note breakdown — are saved alongside.

Standalone: `python student_quiz.py`

### 5.2 Quiz — Haptic Guidance

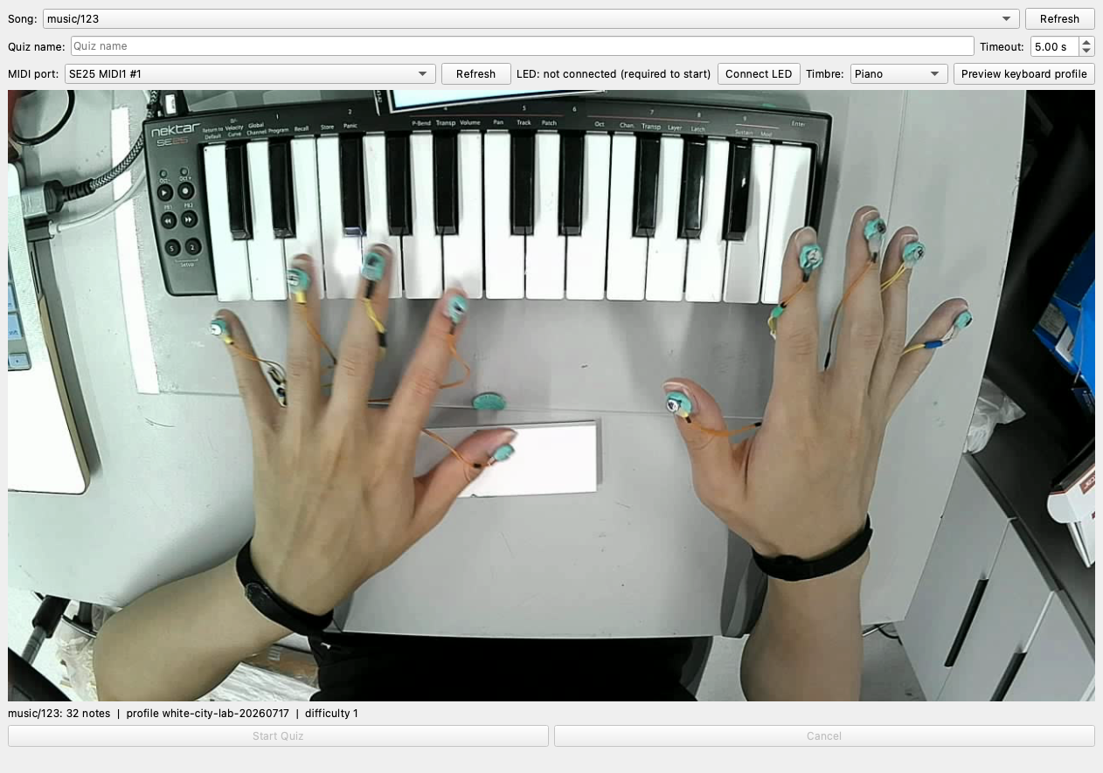
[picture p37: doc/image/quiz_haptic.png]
Quiz — Haptic Guidance


Identical to the above, except the finger is conveyed by a vibration motor on
that finger's nail instead of the on-screen cue. Same drive strength as
[Haptic Vibrator Test](#23-haptic-vibrator-test), from `config.json`'s haptic
block.

Standalone: `python student_quiz_haptic.py`

---

## 6. Main User Study

The formal experiment. These two windows have no standalone entry scripts —
open them from the launcher.

The three feedback conditions are **A** key-light only, **B** visual finger
cue, **C** vibrotactile finger cue.

### 6.1 Participant Trial Schedule

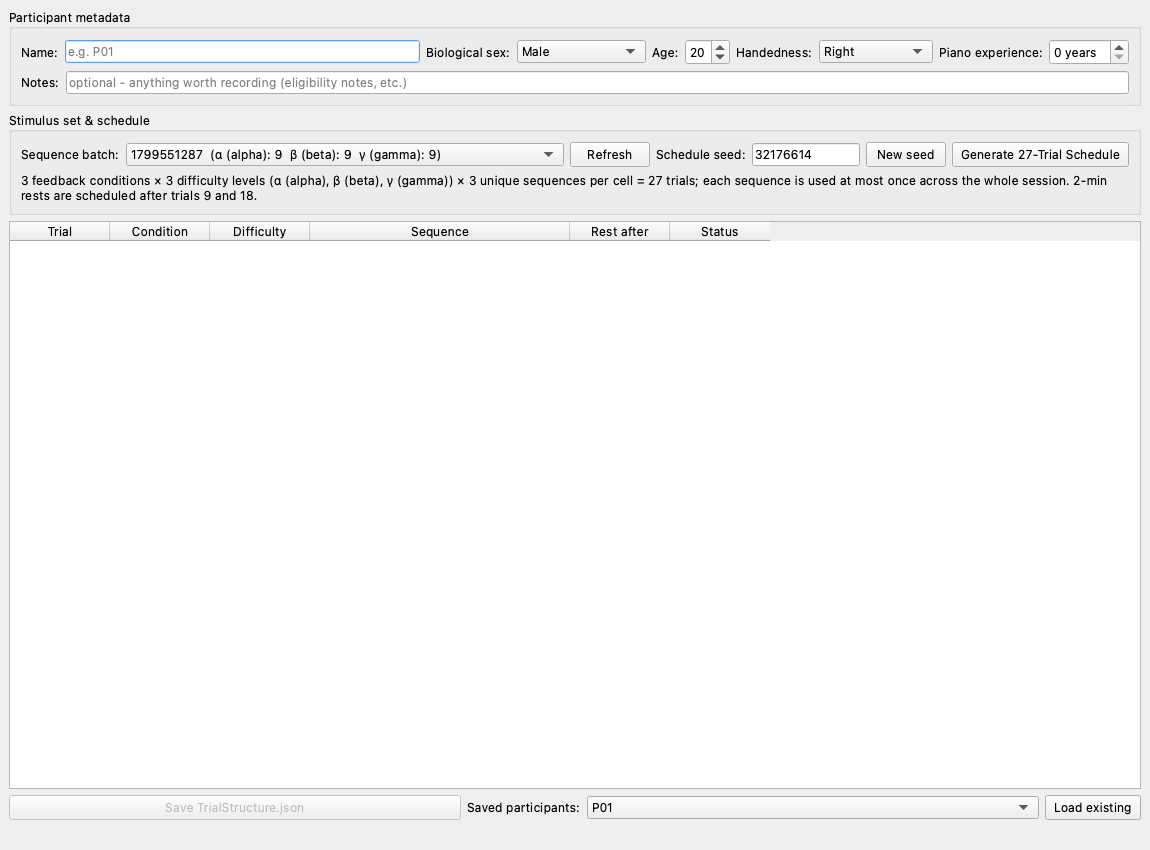
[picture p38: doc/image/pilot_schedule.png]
Participant Trial Schedule


Builds and saves one participant's randomised 27-trial schedule.

1. Fill in the **participant metadata**: name/ID, biological sex, age,
   handedness, piano experience, and any notes.
2. Pick the **Sequence batch** — this locks the participant to one generated
   batch under `data/sequence/`.
3. Set the **Schedule seed** (or press **New seed**), then **Generate 27-Trial
   Schedule**.

3 feedback conditions × 3 difficulty levels × 3 unique sequences per cell =
27 trials; each sequence is used at most once across the whole session, and
2-minute rests are scheduled after trials 9 and 18.

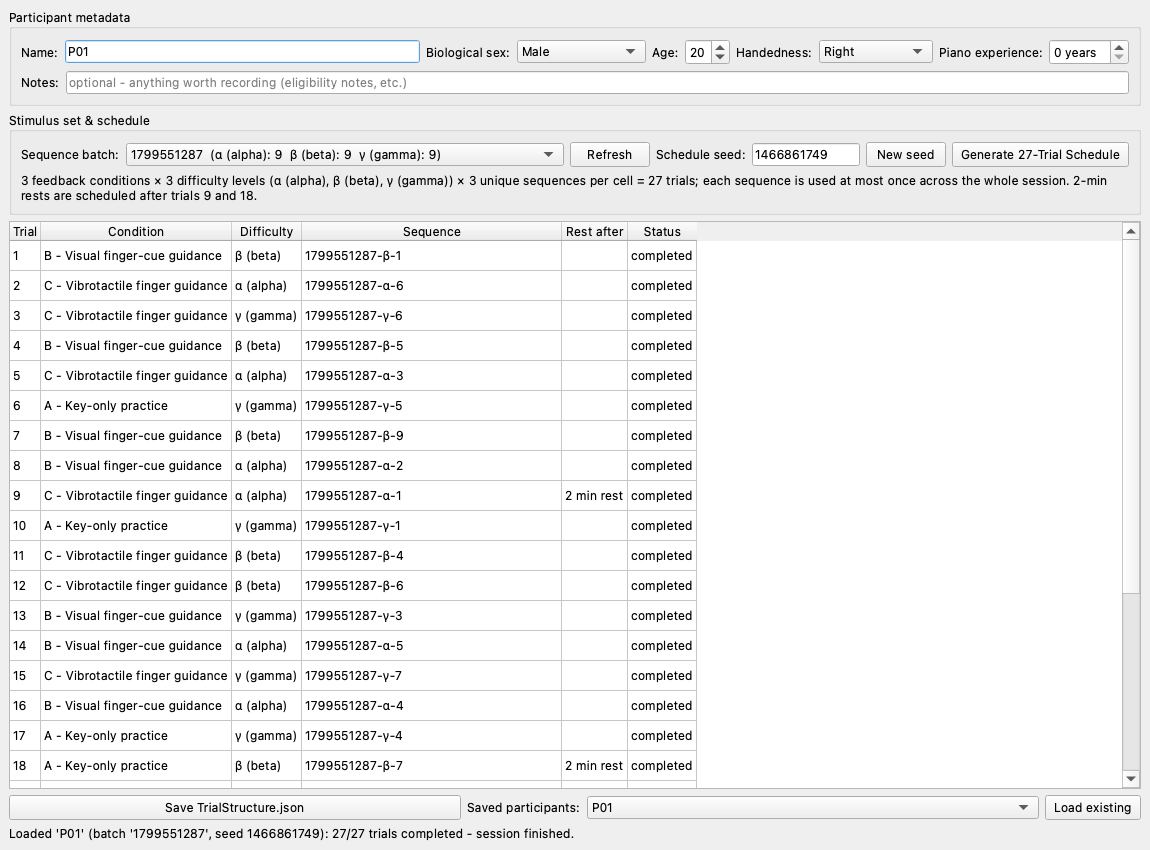
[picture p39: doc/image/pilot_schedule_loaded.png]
Participant Trial Schedule — a generated schedule


**Save TrialStructure.json** writes it to
`data/MainUserStudy/<participant>/TrialStructure.json`. **Load existing** with
a participant selected reopens a schedule you already made.

### 6.2 Formal Experiment Session

This button opens **three windows at once**.

**1 — Session controller.**

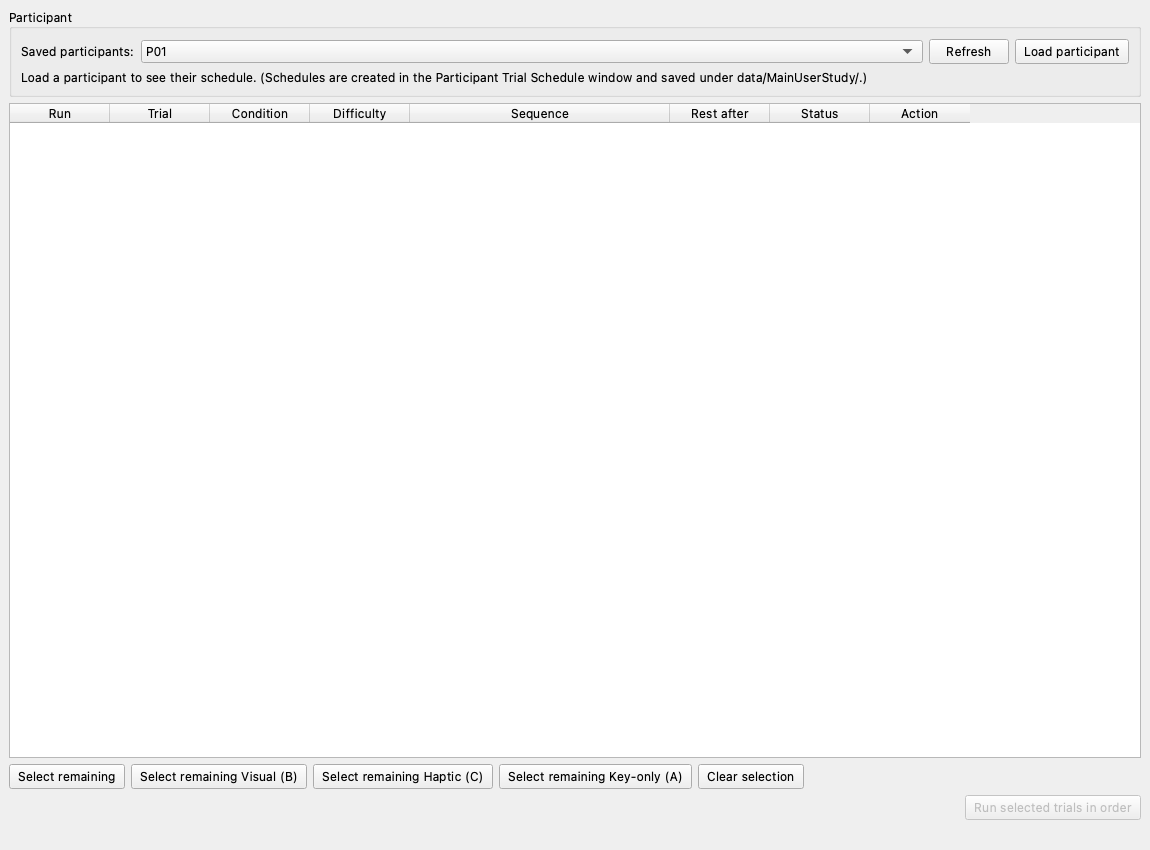
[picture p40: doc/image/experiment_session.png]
Formal Experiment Session — session controller


**Load participant** brings in a saved `TrialStructure.json` and the table
shows every trial's live status. Each row has a tick box and its own **Start**
button. The shortcut buttons tick the remaining trials of one condition
("Select remaining Visual (B)", and so on), and **Run selected trials in
order** walks the ticked trials smallest-index-first, pausing for a manual
Continue between trials — with the 2-minute rest countdown after trials 9 and
18.

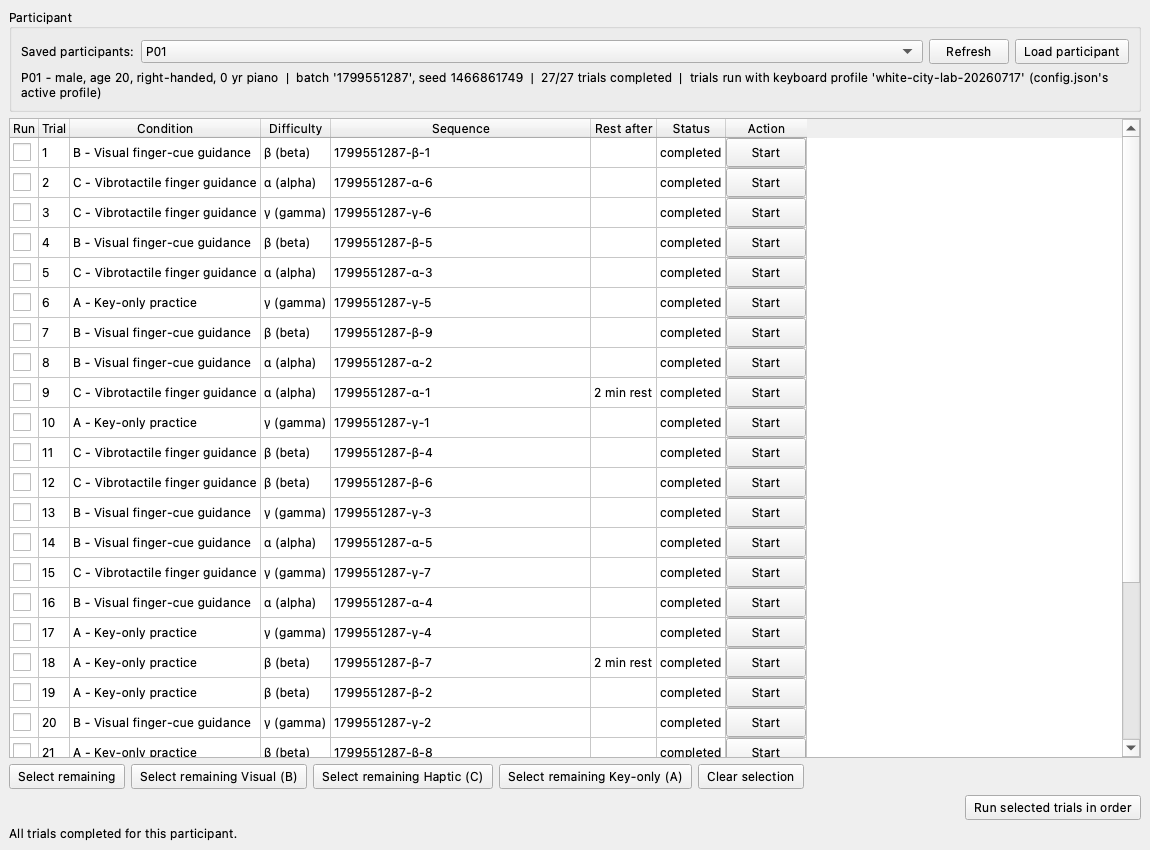
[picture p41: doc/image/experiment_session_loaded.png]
Formal Experiment Session — loaded participant


Every status change is written straight back to `TrialStructure.json`, so a
crashed session reloads with its exact progress and resumes from the first
non-completed trial.

**2 — Trial runner.**

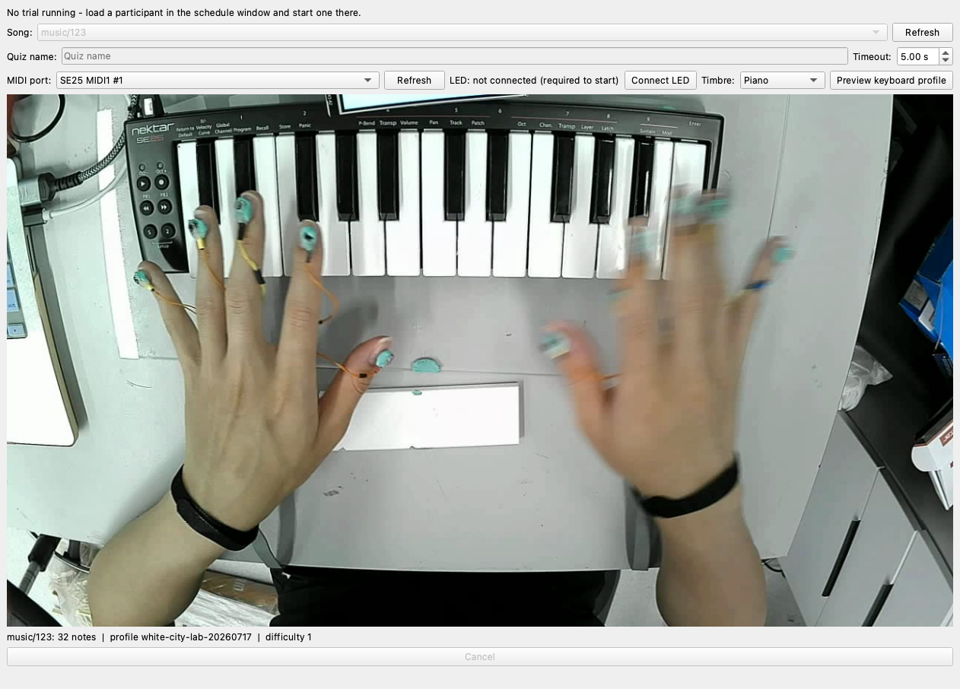
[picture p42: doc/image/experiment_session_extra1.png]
Formal Experiment Session — trial runner


The quiz window re-purposed for scheduled trials. Connect the LED strip and
pick the MIDI port, timbre and timeout **here, once** for the session, and use
**Preview keyboard profile** to confirm the camera still matches the
calibration before the first trial. The song and quiz-name fields are driven
by the schedule, not by you.

Every trial records an ordinary quiz under `data/quiz/`, named
`<participant>-T<index>-<condition><level>` — a rerun appends `-r2`, `-r3`, …
so no attempt's data is ever overwritten. That means the section 7 analysis
tools work on study trials unchanged. The per-trial analysis popup is
suppressed mid-session; batch the analysis afterwards.

**3 — Participant-facing cue screen.**

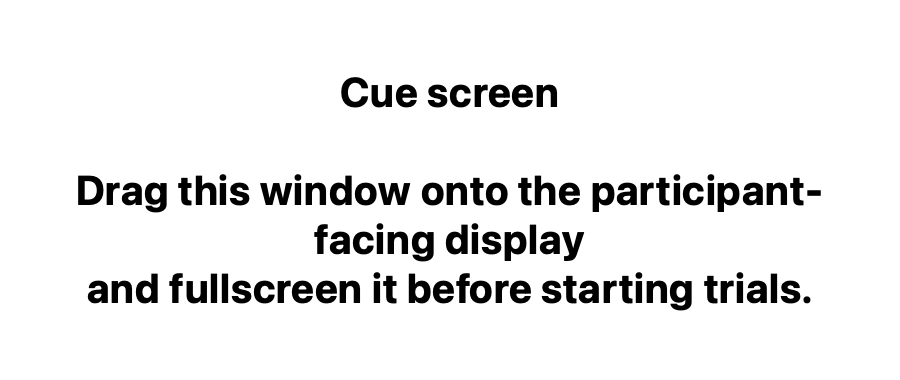
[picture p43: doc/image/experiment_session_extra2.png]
Formal Experiment Session — the cue screen


Created once per session, so you drag it onto the external display and
fullscreen it **one time** instead of reopening it every trial. Condition B
draws the visual finger cue on it; conditions A and C show only a status line,
so no visual finger cue can leak into them.

> Trials always run with `config.json`'s `active_keyboard_profile`. The
> `keyboard_profile` stored inside `TrialStructure.json` is *not* used at run
> time — it only records which profile limited the generator's key range when
> the schedule was made.

---

## 7. Data Analysis

The workflow is a pipeline, and the buttons are in the order you use them:
score the trials, export the participant, then analyse one participant, the
group, and finally the model.

Every stored time in the codebase is an absolute Unix epoch timestamp — no
ISO strings and no recorder-relative clocks.

### 7.1 Quiz Analysis

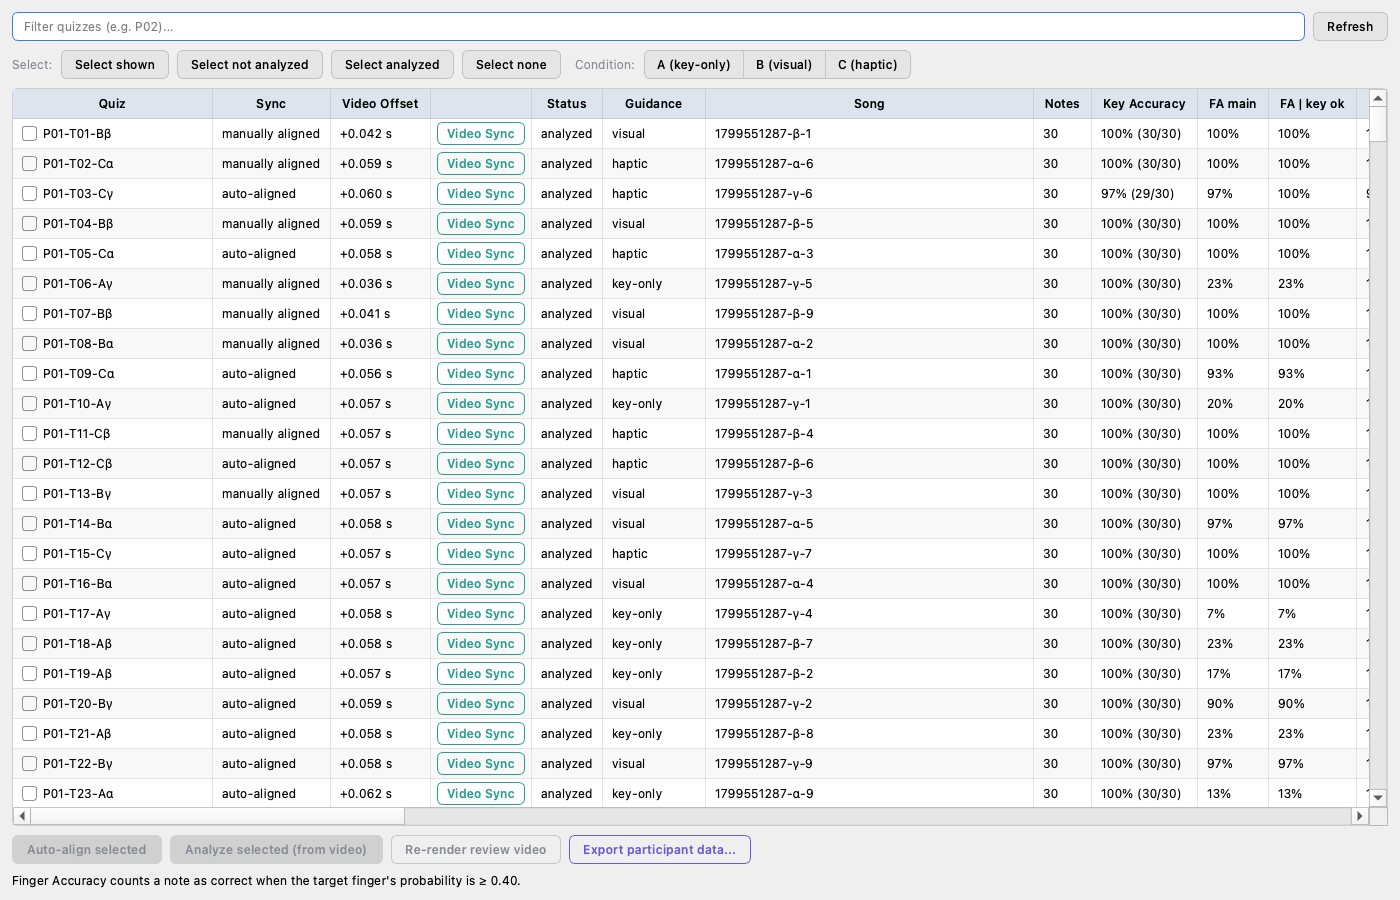
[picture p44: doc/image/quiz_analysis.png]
Quiz Analysis


The per-trial hub. Every saved quiz is a row in a checkable table, with the
full outcome measures as columns: key accuracy, the three finger-accuracy
views (FA main = key ∧ finger over all events, the primary measure; FA | key
ok; Note Accuracy | finger ok), stratified reaction times, timeout and
wrong-key counts, the carry-over review state, QC extra-press counts,
same-hand vs hand-switch splits, per-finger FA/TE for `L1`–`L5` / `R1`–`R5`,
and FA under alternative thresholds.

Use the filter box plus **Select shown / not analyzed / analyzed / none**, and
the **A (key-only) / B (visual) / C (haptic)** buttons, to pick a working set.

The leftmost columns are the ones to read first: **Sync** says whether that
trial's LED anchor was auto- or manually aligned, and **Video Offset** is the
offset it settled on. The table scrolls right through the rest of the measures,
and the line under it states the finger-accuracy threshold the percentages
were counted at.

**What each button does**

| Button | Effect |
|---|---|
| **Video Sync** (per row) | Opens a 3-frame manual alignment window for a trial whose LED flash the detector could not handle. A saved — especially manual — alignment always wins over re-detection. |
| **Auto-align selected** | Persists fresh LED-flash detections as `sync_align.json`, skipping anything already aligned. Behind a confirmation. |
| **Analyze selected (from video)** | Re-runs the detection pipeline and the review-video render per checked quiz. **Behind a confirmation, because it overwrites the detected-finger fields** — manual finger corrections are lost; carry-over validity verdicts are kept. |
| **Re-render review video** | Rebuilds the review copy without re-detecting. |
| **Export participant data…** | Writes `<P>_trials.csv` / `<P>_events.csv` next to that participant's `TrialStructure.json`. |

#### Quiz Detail — one trial, event by event

**Double-click a quiz row** to open it.

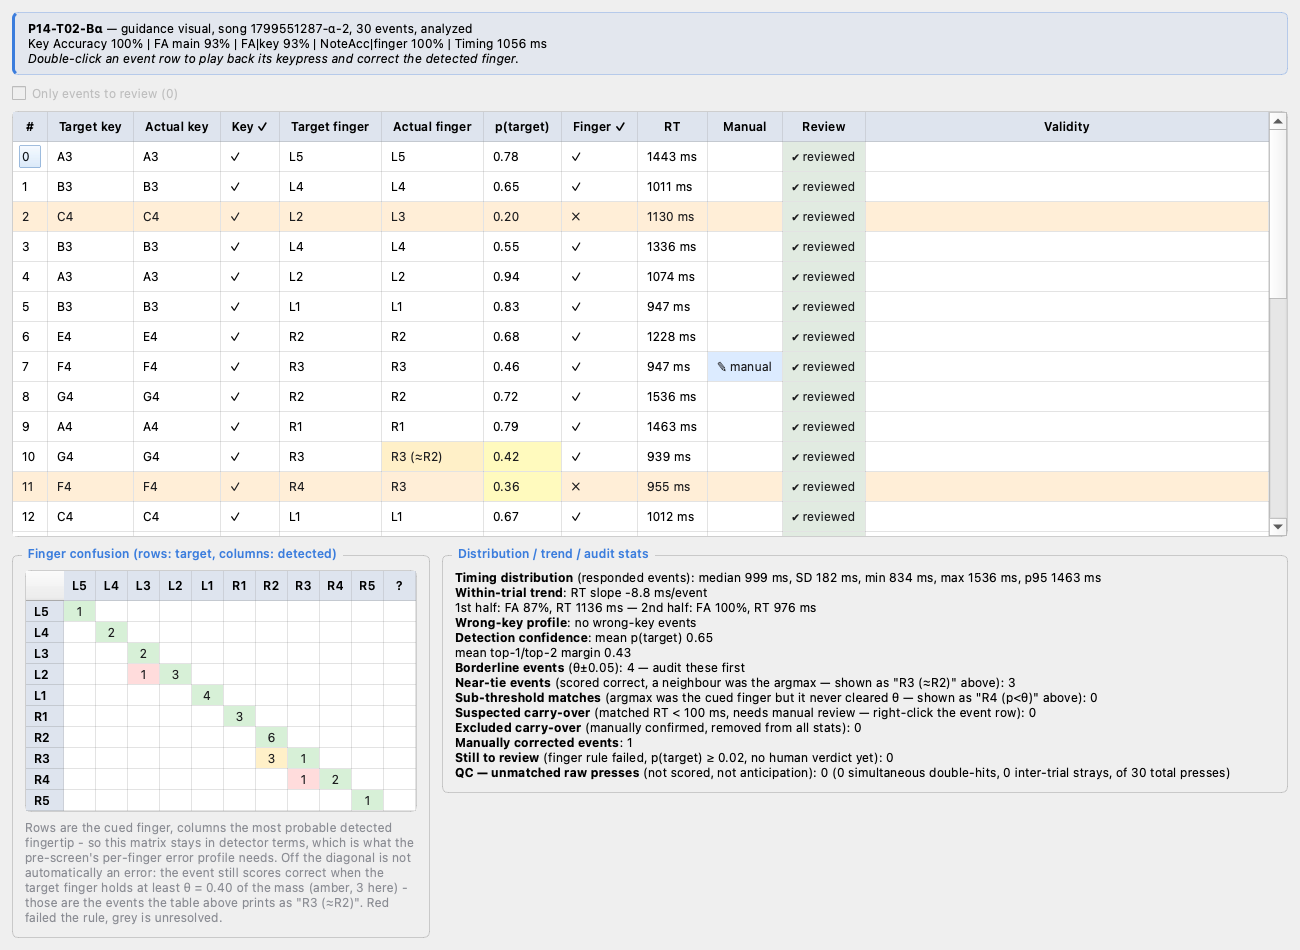
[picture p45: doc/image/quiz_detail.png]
Quiz Detail


Every event of the trial as its own row: the cued key and finger against what
was actually pressed and detected, the detector's confidence `p(target)`, the
reaction time, and whether a human has ruled on it.

**The colours are the whole point of the window** — they say which events
deserve your attention, so you are not reading thirty rows evenly:

| Row / cell | Means |
|---|---|
| Amber row, red ✗ in **Finger ✓** | The finger rule failed: the cued finger never held enough of the probability mass. |
| Yellow `p(target)`, e.g. `R3 (≈R2)` in **Actual finger** | A **near-tie** — scored correct, but a neighbouring finger was the most probable one. Worth a look. |
| `R4 (p<θ)` | A **sub-threshold match**: the cued finger *was* the most probable, but never cleared θ. |
| `✎ manual` in **Manual** | A human has already corrected this event's finger. |
| `review!` in **Validity** | A suspected carry-over — see below. |
| `✔ reviewed` in **Review** | Someone has ruled on it; it is off the review queue. |

**Only events to review** at the top collapses the table to what is still
outstanding, and its count is the size of the job.

Underneath, the **finger confusion matrix** (rows = cued finger, columns =
most probable detected fingertip) shows the trial's error *structure* rather
than its rate, and the **distribution / trend / audit stats** panel names
every count the table's colours encode — borderline events, near-ties,
sub-threshold matches, carry-over suspects, manual corrections, and the QC
tally of raw presses that never matched an event.

> Off the diagonal is **not** automatically an error. An event still scores
> correct while the cued finger holds at least θ = 0.40 of the mass — those
> are the amber `R3 (≈R2)` rows. Red failed the rule; grey is unresolved.

#### Event Review — watch one keypress

**Double-click an event row** in the detail window.

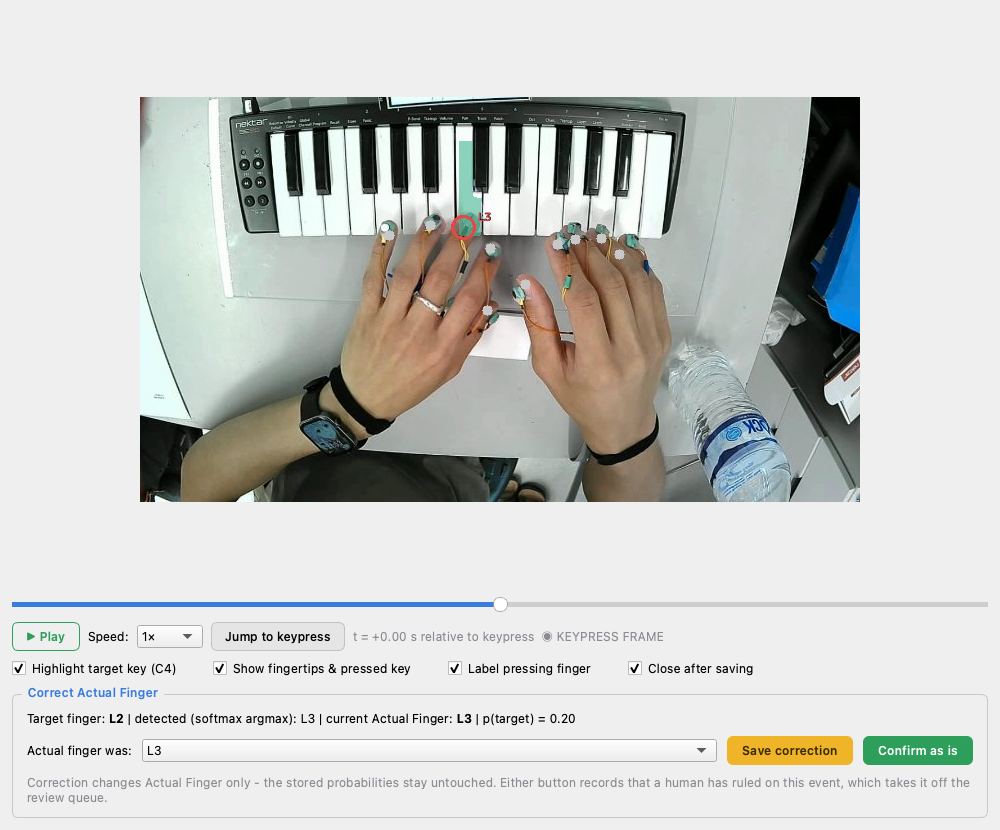
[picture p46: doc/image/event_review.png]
Event Review


The recording around that keypress, ±5 s, so you can see for yourself which
finger pressed the key. The target key is tinted, every tracked fingertip is
dotted, and the finger the detector chose is circled and labelled.

- **Play** / **Speed** / the scrubber move through the clip; **Jump to
  keypress** returns to the moment itself, marked `KEYPRESS FRAME`.
- The four tick boxes turn each overlay off, for when an overlay is covering
  the thing you are trying to see.
- **Correct Actual Finger** states the disagreement in one line — cued finger,
  what the detector chose, and how much probability the cued finger got — then
  lets you set what actually happened.

**Save correction** records a different finger; **Confirm as is** agrees with
the detector. Either one counts as a human verdict and takes the event off the
review queue. A correction changes `actual_finger` **only** — the stored
probabilities are never rewritten, so the detector's original opinion survives
as the audit trail.

#### Carry-over review

A matched response faster than 100 ms cannot be a reaction to its cue — in
practice these are the tail of the previous event's presses crossing the gap.
Such events are flagged `review!` in the Validity column and are **never**
auto-labelled: only a human sets validity, and the code merely nominates
suspects.

**Right-click the event row** for the verdict. The menu offers *Confirm as
invalid carry-over (exclude from RT & accuracy)*, or, on an event already
excluded, *Restore event (mark valid again)*. A confirmed carry-over is
dropped from every statistic — reaction time and accuracy alike — and
re-counted as `excluded_carryover`. Timed-out events have no matched response,
so there is nothing to rule on and no menu appears.

Excluding an event moves every headline number for the trial, so the window
rewrites `results.json` and re-derives the cached summary in the same step.

> **Export is the hand-off.** Group Analysis reads the exported CSVs, not
> `results.json`. Re-run **Export participant data** after any round of finger
> corrections or carry-over verdicts, or the group numbers will be stale.

Standalone: `python quiz_analysis.py`

### 7.2 Participant Analysis

Participant Analysis

Pick a participant and press **Analyze**. Everything here is within-subject
and descriptive — group-level inference is the next window.

Participant Analysis — overview

Ten tabs:

| Tab | Question it answers | |
|---|---|---|
| Overview | The headline per-condition means, side by side | [screenshot](image/participant_analysis_tab1-overview.png) |
| Learning | Progression across the session and the trial 1→3 trend within each condition-level cell | [screenshot](image/participant_analysis_tab2-learning.png) |
| Difficulty | How α / β / γ compare | [screenshot](image/participant_analysis_tab3-difficulty.png) |
| Trade-off | Speed against accuracy | [screenshot](image/participant_analysis_tab4-trade-off.png) |
| Errors | Event-level error breakdown and wrong-key distance | [screenshot](image/participant_analysis_tab5-errors.png) |
| Confusion | Per-condition finger confusion matrices | [screenshot](image/participant_analysis_tab6-confusion.png) |
| Fingers | Per-finger profiles, by physical finger and by homologous finger id | [screenshot](image/participant_analysis_tab7-fingers.png) |
| Finger benefit | The per-finger benefit of the haptic cue | [screenshot](image/participant_analysis_tab8-finger-benefit.png) |
| Timing | Reaction-time distributions | [screenshot](image/participant_analysis_tab9-timing.png) |
| Quality | The data-quality audit, including the carry-over counters | [screenshot](image/participant_analysis_tab10-quality.png) |

Participant Analysis — per-finger profiles

Each tab carries an auto-generated caption. **Export figures + data** writes
300 dpi PNGs and tidy CSVs under `data/MainUserStudy/<P>/figures/`;
**Analyze + export ALL** does every participant in one pass.

### 7.3 Group Analysis (Multi-Participant)

Group Analysis

Tick any subset of exported participants (**Select all** / **Select none**),
then **Analyse selected participants**.

Group Analysis — overview

Thirteen tabs:

| Tab | Question it answers | |
|---|---|---|
| Overview | The group-level headline numbers | [screenshot](image/group_analysis_tab1-overview.png) |
| Condition × Difficulty | The factorial picture | [screenshot](image/group_analysis_tab2-condition-difficulty.png) |
| Contrasts | Paired condition contrasts | [screenshot](image/group_analysis_tab3-contrasts.png) |
| Trade-off | Descriptive speed-accuracy trade-off | [screenshot](image/group_analysis_tab4-trade-off.png) |
| Learning / order | Learning and order trends | [screenshot](image/group_analysis_tab5-learning-order.png) |
| Condition A strategy | What participants did when free to choose fingering | [screenshot](image/group_analysis_tab6-condition-a-strategy.png) |
| Errors | Event-outcome composition | [screenshot](image/group_analysis_tab7-errors.png) |
| Fingers | Homologous per-finger profiles | [screenshot](image/group_analysis_tab8-fingers.png) |
| Finger confusion | Group confusion structure | [screenshot](image/group_analysis_tab9-finger-confusion.png) |
| RM-ANOVA | The Condition × Finger repeated-measures ANOVA | [screenshot](image/group_analysis_tab10-rm-anova.png) |
| Accuracy GLMM | The accuracy sensitivity analysis | [screenshot](image/group_analysis_tab11-accuracy-glmm.png) |
| Finger benefit | Compensation / equalisation / weakest-finger analyses | [screenshot](image/group_analysis_tab12-finger-benefit.png) |
| Quality | The data-quality audit | [screenshot](image/group_analysis_tab13-quality.png) |

Group Analysis — repeated-measures ANOVA

All of it reads the reviewed-and-exported `<participant>_{trials,events}.csv`
files, using the same final verdicts and validity rules as the
single-participant window — so the two can never disagree.

### 7.4 Computational Model Analysis

Computational Model Analysis — before fitting

A model of **which finger acted**, fitted to the study's events and then made
to predict events it has never seen. The other two windows describe what
happened; this one asks whether one mechanism accounts for it, and whether
that mechanism generalises to a participant the model has not met.

1. **Select all** (or tick a subset of participants) and press **Fit model**.
   The two tick boxes above it are part of the fit: *Estimate the habitual
   prior from Condition A alone*, and *Cross-validate (leave one participant
   out)* — the latter refits once per held-out participant, which is most of
   why this takes **tens of minutes** on a full set. The window stays open
   alongside other tools for exactly that reason.
2. **Run out-of-sample prediction** becomes available once a fit exists, and
   fills the third panel. Its own tick boxes add the personalised prediction
   (from that participant's own Condition A) and the within-participant trial
   split.
3. **Save fitted model** / **Load fitted model** let you come back to a fit
   without repeating it. **Reset** clears the state.
4. **Export summary figure** and **Export figures + data** write to
   `data/MainUserStudy/model_figures/`.

Computational Model Analysis — fitted over 20 participants

The header line is the fit's identity — model, participants, events,
parameters — followed by its log-likelihood and, in red, the **identifiability
note**: which parameters the data can only bound rather than estimate. That
note is the first thing to read, because it says which numbers in the tabs
below are point estimates and which are floors.

| Tab | Contents | |
|---|---|---|
| Model Summary | What the model does, what it found, and what it predicts, in prose — plus the three summary panels | [screenshot](image/computational_model_tab1-model-summary.png) |
| Error Structure | Where the errors come from, and which cue makes which mistake possible | [screenshot](image/computational_model_tab2-error-structure.png) |
| Habitual Fingering | The Condition-A habitual prior | [screenshot](image/computational_model_tab3-habitual-fingering.png) |
| Selection vs Execution | The reaction-time decomposition | [screenshot](image/computational_model_tab4-selection-vs-execution.png) |

Tick **Show advanced diagnostics** to add the parameter estimates, the model
comparison against simpler alternatives, the identifiability audit and the
per-fold cross-validation behind all of it. The log pane at the bottom names
each fold as it runs, so a long fit visibly progresses.

---

## 8. Tele-training

Guidance delivered over a network: a teacher plays, a relay forwards, and the
student's LED strip and finger motors fire from what the teacher did.

This is the one section whose buttons start **separate processes**, because a
teacher, a student and a relay have to be up at the same time, on different
machines, holding different devices. Nothing in the launcher closes them.

There is deliberately **no shared settings window** — each of the three
programs owns its own settings, because one window showing all three roles'
devices meant everyone was mostly looking at settings that were not theirs.

The full module documentation is [`doc/REMOTE_GUIDANCE.md`](REMOTE_GUIDANCE.md)
(§12 is the user-facing reference), and the relay has its own operator guide
in [`doc/server.md`](server.md).

### 8.1 Trying it on one machine

```bash
python -m server --init      # once: create the SQLite database
```

Then start **Relay Server**, **Teacher Client** and **Student Client** from
this section, in that order. Both clients arrive pre-filled with
`http://127.0.0.1:18765` and their demo account, so the sequence is:
sign in → create/join a room → **Get ready** → **Ready for guidance** →
**Start teaching**.

### 8.2 Relay Server

Starts the FastAPI relay (REST + WebSocket, SQLite, JWT auth) in its own
process, with its own window. If a relay is already answering on that
address, the launcher says so rather than starting a second one that would
fail to bind the port.

`server/` imports nothing from this platform, so it can be copied to a remote
host on its own.

### 8.3 Teacher Client

Teacher Client — control desk

The teacher's control desk. The header tracks which of the three setup steps
you are on, **Settings** holds this machine's own camera / MIDI / profile /
serial ports, and the session page has three tabs:

| Tab | Contents |
|---|---|
| Live studio | Live controls, camera preview, and the Get ready → Start teaching flow |
| Recording library | Pre-recorded sequences to upload and trigger |
| Student results | What came back from the student |

**Chord detection** matches simultaneous notes together; **Record this lesson**
saves the session under `data/music/`. **Get ready** opens the local camera
and MIDI, **Start teaching** begins sending guidance, and Pause / Resume /
Stop control it from there.

Standalone: `python teacher_remote_guidance.py`

### 8.4 Student Client

Student Client

Receives the teacher's key/finger guidance and cues it locally on the
student's own LED strip and finger motors. Its **Settings** dialog is where a
remote student picks their camera, MIDI port and keyboard profile — including
**Preview keyboard profile**, which here opens the camera for one snapshot
because the window holds no camera yet.

Standalone: `python student_remote_guidance.py`

### 8.5 Tele-training Setup Wizard

Tele-training Setup Wizard

**Use this — not the section 1 wizards — to onboard a remote partner.**

A new person joining a session needs a calibration: a pixel mask of their
camera's view of their keyboard, plus that keyboard's key→note mapping. The
Initial Setup wizards produce exactly that, but they *also* write
`config.json`'s top-level `camera`, `midi.port_name` and
`active_keyboard_profile`, and save over an existing profile folder. On a
machine that also runs the formal experiment, that repoints the experiment's
devices and can destroy a calibration a recorded session is scored against.

This wizard produces the profile and **nothing else** — it writes no
`config.json` key at all, not even the `remote_guidance` block. Three steps
across the top:

1. **Camera** — press **Scan for cameras**, pick one, set resolution/fps and
   the flips. Opening the wizard does not open a camera.
2. **Calibration** — the same click-to-fill calibration as section 1.3, into a
   new profile folder.
3. **MIDI mapping** — the same key-by-key mapping as section 1.4.

The new profile is picked up by selecting it in a client's own **Settings**
dialog, which is where choosing devices already lives.

### 8.6 Network Latency Benchmark

Fires synthetic probes along the relayed path to characterise it, and writes
`samples.csv`, `summary.json` and `latency.png` under
`data/remote_guidance/latency/<run>/`. Runs as its own process, with a CLI or
a GUI.

Standalone: `python remote_latency_benchmark.py [--gui]`

### 8.7 Remote Latency Analysis

Remote Latency Analysis

The other half of the pair: where the benchmark fires synthetic probes, this
reads the delays that **real guidance cues actually met**. It opens the
relay's own store (`server/data`), lists the sessions that recorded per-cue
timings, and shows the transport and cue-delivery breakdown for the session
you pick.

One rule shapes the layout, and it is worth knowing before reading a number
off it: **same-clock differences are latencies** and are shown as such (relay
processing, the student's cue pipeline, the visual–haptic skew), while the
cross-machine leg has no synchronised clock behind it, so only its
offset-removed variation — the delivery jitter above the session's own floor
— is reported. There is deliberately no absolute one-way number.

---

## 9. Tools

Housekeeping on data that has already been collected. Neither tool is part of
running a session or analysing one, and neither reads anything the experiment
reads.

Both windows keep running when you open another launcher tool — a conversion
pass is minutes of work and should not be thrown away by a button press.

Each window has a console twin that does exactly the same thing to the same
files: **Scan** is the script's first phase, and **Convert** / **Create
archives** is what answering `1` at its prompt does. The windows add only what
a terminal cannot: a table of what was found, an overall and a per-file
progress bar, a running log, and a **Stop** button.

### Where ffmpeg and 7z come from

Neither program is a Python dependency. Both windows look in two places, in
order:

1. **`runtime/bin/`** — drop `ffmpeg` / `7z` in that folder and nothing has to
   be installed on the machine.
2. **`PATH`**, as installed system-wide.

Each window shows which copy it is using, or a warning naming `runtime/bin` if
it found none, and has a **Re-check** button so a program dropped in there is
picked up without restarting the launcher.

### 9.1 Review Video Compression (ffmpeg)

Review Video Compression

Converts `data/quiz/<attempt>/review.mp4` files that are not already H.264.

1. **Scan review videos** probes every review copy with ffmpeg and reports its
   codec. This only reads.
2. **Convert** re-encodes the ones that need it. **Stop** aborts safely.

The path pattern cannot enter `data/quiz/<attempt>/raw/`, so the original
recordings are outside this tool's scope entirely.

Each conversion pays for its safety twice over: the original is fully decoded
before the rename and the new file fully decoded after it, and the source is
deleted only once the replacement is proved non-empty, H.264, fully decodable
and the same frame count. If anything fails — including you pressing Stop —
the original is put back and the discarded output is kept as
`failed-review.mp4` for you to look at. That is three ffmpeg passes per file,
which is why there is a per-file bar as well as an overall one, and why a
study's worth of reviews is an hour-scale job.

Console twin: `python3 tool_compress_review_videos.py`

### 9.2 Participant ZIP Backup (7z)

Participant ZIP Backup

Creates one `data/quiz-zip/Pxx.zip` per complete participant.

The **table is the preview**, one row per participant, and its **State**
column is the reason that participant is or is not being archived — which
between sessions is usually the question being asked:

| State | Meaning |
|---|---|
| ready | All 27 trials present; will be archived |
| incomplete | Missing trials, named in the row |
| archive exists | `Pxx.zip` already there; skipped |
| temporary archive exists | A previous run left `tmp-Pxx.zip`; remove it by hand to retry |

Only `P01`–`P20` with trials `T01`–`T27` are eligible; `TEST-*`, `remote-*`,
other unexpected names, symlinks in place of trial directories and `.DS_Store`
files at every depth are excluded. Each archive is written first as
`tmp-Pxx.zip` and must pass `7z t` before it is renamed. Nothing existing is
ever overwritten, and no source file is ever deleted or modified.

Console twin: `python3 tool_backup_quiz_to_zip.py`

---

## 10. Validation Experiments

Small hardware-characterisation sweeps, kept separate from the study
protocols. They are what the platform's design constants were measured with.

Each window is a **front panel** wrapped around the unchanged script under
`validation_experiments/`, run on a worker thread so the GUI never freezes
during a multi-minute serial sweep. Every experiment has a full write-up in
its own folder's `README.md`; the shared metric/raw-data layer is documented
in [`doc/validation-experiments.md`](validation-experiments.md).

### The controls, which are the same in all five

LRA Frequency Sweep

| Control | What it does |
|---|---|
| **Motor port** / **ACC sensor id** | Which actuator is driven and which accelerometer is read. The defaults are recommended — change them only when the rig demands it. |
| **Test Buzz** | Drives the selected port at the configured default so you can confirm the port really is the actuator the sensor is taped to. |
| **Plot metric** | Demeaned 3-axis vector RMS (recommended) or the legacy magnitude RMS. **Both are measured every run**, so switching this re-plots the displayed run with no new hardware pass — peak, annotations and colour-bar label all follow the choice. A run saved before raw three-axis samples were kept offers the legacy metric only, and the vector option is disabled rather than faked. |
| **Saved runs** / **Browse…** | On open the preview shows the latest saved run. Any saved CSV can be re-rendered — to a temp file, so saved outputs are never modified. |
| **Start** / **Stop** | Runs the sweep. Progress is shown as steps, with a live console log. |
| **Enlarge Chart** | The in-window preview is a thumbnail. Clicking it opens the PNG at full resolution with fit / 100% / zoom, Ctrl+scroll and panning. **One** such window is shared by every validation experiment — clicking a chart in another window swaps the image instead of piling up windows. |
| **Show Statistics** | The console-style text statistics for the loaded run. |

> **Physical setup matters more than any setting here.** The accelerometer
> must be glued or taped to the motor under test so the two move as one unit,
> and the pair fixed to a rigid desk surface. A loose sensor or a
> free-floating rig invalidates every measurement.

Runs are saved as timestamped CSV / PNG / `raw_acc.npz` / `meta.json` sets
under `data/validation_experiments/<experiment>/`. The `raw_acc.npz` holds the
run's full three-axis samples, so both intensity metrics and every chart can
be regenerated offline.

### 10.1 Actuator Spectrogram (ERM/LRA)

Actuator Spectrogram

A 2-D drive-frequency × amplitude intensity map — where in that plane the
actuator actually produces vibration.

### 10.2 LRA Frequency Sweep (Resonance)

*(Pictured in the section above.)* Finds the mounted LRA's resonant frequency:
a coarse 5 Hz pass over 100–350 Hz, then a fine 1 Hz pass around the peak. This is the measurement
behind `config.json`'s `haptic.lra.default_frequency`. The sweep always covers
the full range — the configured default never narrows what is measured.

### 10.3 LRA Amplitude Sweep (Intensity)

LRA Amplitude Sweep

Vibration intensity against drive amp at a fixed frequency — the measurement
behind `haptic.lra.default_amp`.

### 10.4 Motor → ACC Delay (LRA/ERM)

Motor to ACC delay

Command-to-vibration latency: how long after the drive command the
accelerometer first sees motion. Produces a four-panel summary, which is
worth opening with **Enlarge Chart** — it carries far too much detail to read
at thumbnail size.

### 10.5 Adhesion Vibration Comparison (LRA)

Adhesion Vibration Comparison

Relative vibration transfer of three mounting adhesives, LRA only, with its
own three-run comparison analysis — how much of the actuator's output
actually reaches the nail depending on what holds it there.

---

## 11. Rhythm Experiment

A **separate study**. The Main User Study asks which cue modality teaches
best; this one asks what survives when a cue is taken away. One 15-note
melody, played 19 times, with guidance withdrawn on a schedule:

    Training ×5 → Probe 1 → Training ×5 → Probe 2 → Training ×5 → Probe 3 → Final test

| Phase | Backlight | Haptic | Task | n |
|---|---|---|---|---|
| Training | on | on | cue/response | 15 |
| Probe | on | off | performance | 3 |
| Final test | off | off | performance | 1 |

The design, the measures and the analysis plan are written up in
[`doc/RHYTHM_EXPERIMENT.md`](RHYTHM_EXPERIMENT.md); the generator has its own
guide in [`doc/melody-generator.md`](melody-generator.md).

> **It cannot disturb any earlier experiment**, and that is structural rather
> than a convention: this section shares no code with the sequence generator,
> writes no `config.json` key, no keyboard profile, and nothing under
> `data/sequence/`, `data/music/` or `data/MainUserStudy/`. Its melodies are
> not registered with the song library, so one can never appear in the song
> pickers used by the other studies. The two studies meet only in the shared
> `data/quiz/` folder, where the `rhythm-` prefix separates them.

The five buttons are in the order a session uses them.

### 11.1 Rhythm Melody Generator (15-note)

Rhythm Melody Generator

1. Pick a **seed**, a **key** and a **hand position**. The note range comes
   from the chosen five-finger hand position, not from the calibrated
   profile — so this does not care which profile is selected.
2. **Preview (writes nothing)** generates and shows the melody on the
   on-screen piano, with the target finger lit for each note. Play / Pause /
   Stop and the seek bar are the Song Playback controls, shared so a melody
   looks and sounds the same here as when it is replayed off disk.

Rhythm Melody Generator — a previewed melody

3. **Generate & Save files** writes the `.mid` / `.json` / `.csv` / `.txt`
   stimulus set into `data/rhythm_experiment/`. **Change folder…** and
   **Open folder** control where.

### 11.2 Playback Rhythm Melody

Playback Rhythm Melody

Read-only replay of what the generator already wrote: pick a melody, and it
plays on the same piano, reading the `.json` for the fingering and the exact
note-on/note-off times plus the `.mid` as a cross-check.

### 11.3 Rhythm Trial Schedule

Rhythm Trial Schedule

Fill in the participant's metadata, pick which melody under
`data/rhythm_experiment/` to lock them to, and **Generate 19-Trial Schedule**.

Rhythm Trial Schedule — a loaded participant

Simpler than the Main User Study's equivalent in one important way: the trial
order here is **fixed by the design**, not sampled, so there is no batch to
choose, no seed to draw and nothing to reproduce. The one real choice is which
melody the participant learns — and because they play the same one 19 times,
that choice is made once, here, and frozen into their file.

**Save TrialStructure.json** writes to
`data/RhythmStudy/<participant>/TrialStructure.json`.

### 11.4 Rhythm Experiment Session

This button opens **two** windows — the session controller and the trial
runner. There is no participant-facing cue screen, because this study has no
visual guidance: the only cues are the keyboard backlight and the haptic
motors.

Rhythm Experiment Session — session controller

**Load participant** brings in the saved schedule and the table shows all 19
trials with their live status. Every row has a tick box and a **Start**
button; the shortcuts are phase-shaped here — **Select remaining Training**,
**Select remaining Probes**, **Select Final test** — and **Run selected trials
in order** walks the ticked trials smallest-index-first, pausing for Continue
between them.

Rhythm Experiment Session — the 19-trial withdrawal schedule

The **Backlight** and **Haptic** columns are the design made visible: `on/on`
through Training, `on/OFF` at each Probe, `OFF/OFF` for the Final test.

Rhythm Experiment Session — trial runner

Each trial is recorded as an ordinary quiz under `data/quiz/` with a `rhythm-`
prefix, byte-compatible with any other quiz; this study's extra per-note
fields go in a sidecar file rather than into `results.json`.

### 11.5 Rhythm Group Analysis

Rhythm Group Analysis

The whole analysis stage in one window — deliberately one, not the main
study's three, because this study asks one question and answers it from one
table of three probes.

1. Tick the participants (**Select all** / **Select none**).
2. Set the **onset tolerance** for the combined score (default 200 ms).
3. **Run analysis** prints the summary.

Rhythm Group Analysis — summary

The summary states the question in plain words, then gives the primary
Probe 1 vs 2 vs 3 comparison (finger accuracy, absolute inter-onset-interval
error) and the secondary measures. It names its own limits — where a measure
has too few participants for a test, it says so instead of reporting one.

**Export CSVs, statistics & figures** writes everything under
`data/RhythmStudy/group_figures/`.

---

## 12. Demo & About

### 12.1 Demo Mode

Demo Mode

Opens the platform's participant- and tele-training-facing windows so they can
be photographed for slides, a report or a poster — with **no rig, no relay and
no second person**. It adds no behaviour of its own: each window is the real
one, shown the way it looks in use.

Tick any combination and press **Open selected**:

| Option | What opens |
|---|---|
| **Visual Cue screen** | The real finger-cue screen, with a finger you pick already highlighted, in either the dot or the hand style |
| **Keyboard backlight (LED)** | The real Virtual Piano → LED window. With "backlight always on" ticked, pick a key there to light one LED steadily for a photo — no clicking |
| **Teacher Client (offline)** | The tele-training teacher window in demo mode: straight to its session page, no server, no login, no peer |
| **Student Client (offline)** | The same for the student |

The camera and MIDI still open locally from the normal in-window buttons, so a
photo shows the live view. Two windows cannot share one camera — give the
Teacher and Student different camera indices to photograph both live at once.

The panel stays open after **Open selected**, so you can add more windows or
re-open one you closed. The windows it opens are exempt from the
one-tool-at-a-time rule — showing several at once is the whole point — and
they close with the launcher.

The keyboard backlight window in demo mode

### 12.2 About

About

The platform's front matter, copied verbatim from the dissertation: the title
and subtitle, the author and supervisors, the abstract, the acknowledgements,
and the public repositories.

| Tab | Contents | |
|---|---|---|
| Overview | What the platform is, and who made it | [screenshot](image/about_tab1-overview.png) |
| Abstract | The dissertation abstract | [screenshot](image/about_tab2-abstract.png) |
| Acknowledgements | As written in the report | [screenshot](image/about_tab3-acknowledgements.png) |
| Resources | The two public repositories | [screenshot](image/about_tab4-resources.png) |

It claims no hardware, so it stays open beside whatever tool you are using,
and re-clicking About raises it rather than opening a second copy.

---

## Where files are written

Every path is relative to `main/`.

| Path | Written by | Contents |
|---|---|---|
| `config.json` | Sections 1.2, 1.3, 1.4, 1.6, 1.7, 2.5 | Camera, MIDI port, active profile, visual cue style, haptic defaults, accelerometer sensor id, the tele-training block |
| `data/keyboard-profile/<name>/` | Keyboard Calibration Wizard (1.3), MIDI Mapping Wizard (1.4), Tele-training Setup Wizard (8.5) | `keyboard_template.json`, `keyboard_key_map.png`, `midi_mapping.json` |
| `data/music/<song>/` | Song Recording Wizard (3.1), Teacher Client with recording on (8.3) | The recording plus its fingering-annotated score |
| `data/sequence/<batch>/` | Experiment Sequence Generator (4.1) | Generated stimulus sequences |
| `data/sequence_validation/<batch>/` | Experiment Sequence Generator (4.1) | The difficulty-validation output for a batch |
| `data/quiz/<attempt>/` | Quizzes (5.1, 5.2), Formal Experiment Session (6.2), Rhythm Experiment Session (11.4) | `raw/` video + MIDI, `results.json`, `meta.json`, `review.mp4`, and the sync anchors |
| `data/quiz-zip/Pxx.zip` | Participant ZIP Backup (9.2) | Participant-level backups; never used as live input |
| `data/MainUserStudy/<P>/` | Participant Trial Schedule (6.1), Quiz Analysis export (7.1), Participant Analysis (7.2) | `TrialStructure.json`, `<P>_trials.csv`, `<P>_events.csv`, `figures/` |
| `data/MainUserStudy/group_figures/` | Group Analysis (7.3) | Group figures and CSVs |
| `data/MainUserStudy/model_figures/` | Computational Model Analysis (7.4) | Fitted-model figures, CSVs and the prediction tables |
| `data/validation_experiments/<experiment>/` | Section 10 | Timestamped CSV / PNG / `raw_acc.npz` / `meta.json` per run |
| `data/remote_guidance/latency/<run>/` | Network Latency Benchmark (8.6) | `samples.csv`, `summary.json`, `latency.png` |
| `data/rhythm_experiment/` | Rhythm Melody Generator (11.1) | `.mid` / `.json` / `.csv` / `.txt` per melody |
| `data/RhythmStudy/<P>/` | Rhythm Trial Schedule (11.3) | `TrialStructure.json` |
| `data/RhythmStudy/group_figures/` | Rhythm Group Analysis (11.5) | Tables, statistics and figures |

---

## If something looks wrong

**The key masks no longer sit on the physical keys.** The camera or the
keyboard has moved. A profile is only a pixel mask of one camera position, so
re-run the [Keyboard Calibration Wizard](#13-keyboard-calibration-wizard).
[Keyboard Profile Selection / Region Preview](#15-keyboard-profile-selection-region-preview)
is the fastest way to check, and **Preview keyboard profile** does the same
from inside the quiz and trial-runner windows.

**Finger accuracy is unexpectedly low for one trial.** Check the alignment
before the detection: open **Video Sync** for that row in
[Quiz Analysis](#71-quiz-analysis). Per-trial camera start-up error is real,
and a mis-detected LED flash moves every event.

**Two keyboards of the same model, and the wrong one responds.** The `#1` /
`#2` suffix is enumeration order, not device identity, and it can change when
something is replugged. `python test-script/MIDI.py` listens on every port at
once and prints which label your key press arrived on.

**A launcher tool closed itself when I opened another.** That is the
one-tool-at-a-time rule — most of these claim the camera or the MIDI keyboard.
The Analysis and Tools windows are the exceptions and stay open.

**A window says it cannot find ffmpeg / 7z.** Drop the executable into
`runtime/bin/` and press **Re-check**; nothing has to be installed
system-wide.

**Group Analysis disagrees with what I corrected in Quiz Analysis.** Group
Analysis reads the exported CSVs, not `results.json`. Re-run **Export
participant data** after any round of finger corrections or carry-over
verdicts.

---

## How these screenshots were made

`main/test-script/capture_manual_screenshots.py` renders every window in this
manual offscreen and writes the PNGs to `doc/image/`. It is a documentation
tool, not a test, and it exists so the manual can be regenerated after a UI
change instead of being re-photographed by hand.

It runs against a **copy** of the project rather than the live one, with the
camera, serial ports and MIDI ports stubbed, so a capture run cannot open a
device or write to real data. See that file's docstring for how to point it at
a sandbox and re-run it.

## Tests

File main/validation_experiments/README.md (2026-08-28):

# Validation Experiments — shared layer

Small hardware-validation / calibration experiments that inform the main
user study's design constants but are not part of the main protocol
(launcher section **10. Validation Experiments**). One subfolder per
experiment, each with its own full write-up:

| Folder | Experiment |
|---|---|
| `lra_resonance_intensity_calibration/` | LRA frequency sweep (resonance) + amplitude sweep (cue intensity) |
| `actuator_spectrogram/` | 2-D drive-frequency × amp vibration-intensity map (ERM/LRA) |
| `motor_acc_delay_experiment/` | command → vibration onset latency **and** settling time (LRA/ERM) |
| `adhesion_vibration_comparison/` | relative vibration transfer of three mounting adhesives (Blu Tack / double-sided tape / cosmetic adhesive), LRA-only |

Two modules at this level are shared by all of them:

| Module | Contents |
|---|---|
| `rig.py` | serial-rig helpers: Teensy port detection, the `E` identity handshake, `send()`, the `ACC,<id>,x,y,z` parser, and `collect_samples()` — the one accelerometer collector |
| `acceleration_metrics.py` | the vibration-intensity metrics, the counts → m/s² conversion, the metric naming/registry, and the lossless raw three-axis sample store |

This file documents `acceleration_metrics.py`, because every
accelerometer experiment now computes, stores and plots its intensities
through it. Read it once here rather than four times in the experiment
READMEs.

---

## 1. The two intensity metrics

Every measurement window is scored with **both** metrics. Which one a
chart is drawn with is a **plot-time** choice, not a measurement-time
one — the run stores both numbers *and* the raw samples they came from.

### 1.1 Legacy magnitude RMS — `legacy_magnitude_rms`

The project's original formula, unchanged, kept so historical results
stay directly comparable:

```
magnitude_i = sqrt(x_i² + y_i² + z_i²)
legacy_magnitude_rms = sqrt( mean( (magnitude_i − baseline_magnitude)² ) )
```

`baseline_magnitude` is the mean `|a|` of a separate quiet (motor-off)
window, re-measured during the run — it is essentially gravity
(≈ 1000 counts at ±2 g, 1 count = 1 mg).

**Known weakness.** `|a|` is only *second-order* sensitive to vibration
perpendicular to gravity: `sqrt(g² + v²) ≈ g + v²/2g`, so a 40-count
horizontal vibration moves the magnitude by well under a count while the
same vibration along gravity moves it by 40. The metric therefore mixes
the rig's *mounting orientation* into every intensity it reports. (This
is the same blind spot the motor→ACC delay experiment documented years
ago as the reason its detector never used `|a|`.)

### 1.2 Demeaned three-axis vector RMS — `vector_rms` (recommended, default)

Computed per window, with no external baseline:

```
mean_x = mean(x)   mean_y = mean(y)   mean_z = mean(z)

vector_rms = sqrt( mean( (x_i − mean_x)² + (y_i − mean_y)² + (z_i − mean_z)² ) )
```

Equivalently, from the per-axis RMS values:

```
rms_x = sqrt(mean((x_i − mean_x)²))      (likewise rms_y, rms_z)
vector_rms = sqrt(rms_x² + rms_y² + rms_z²)
```

Subtracting each axis's own mean removes **gravity, the sensor's static
bias and the mounting pose** in one step, so the number is the AC energy
of the vibration in any direction. It is the recommended metric and the
**default** for new runs and new plots.

### 1.3 Choosing between them

| | Legacy magnitude RMS | Demeaned 3-axis vector RMS |
|---|---|---|
| needs a separate baseline window | **yes** | no |
| rejects gravity / static bias | partly (via the baseline) | **fully** |
| sensitive to vibration ⟂ gravity | **no** (second order) | **yes** |
| unchanged if the rig is remounted in another pose | no | **yes** |
| available for pre-2026-07 runs | **yes** | no (needs per-axis samples) |
| default for new runs | no | **yes** |

Use the **vector RMS** unless you are explicitly reproducing or
comparing against a historical number, in which case use the **legacy**
metric on both sides of the comparison.

The two can rank cells differently — that is the point, not a bug. The
run log prints where the *other* metric peaks, so a divergence is
visible without re-plotting.

### 1.4 Units and naming

```
value_ms2 = value_counts × ms2_per_count      (ms2_per_count = 0.00980665)
```

Conversion happens exactly once, in
`acceleration_metrics.counts_to_ms2()`. **Every stored field name ends
in `_counts` or `_ms2`**; the bare name `rms` is not used anywhere any
more. Chart axis and colour-bar labels are generated from the metric
name, so a saved figure always says which metric it shows:

```
Legacy magnitude RMS acceleration (m/s²)
Demeaned 3-axis vector RMS acceleration (m/s²)
```

---

## 2. Public interface

```python
from validation_experiments.acceleration_metrics import (
    compute_legacy_magnitude_rms,   # (samples, baseline_magnitude) -> counts
    compute_demeaned_vector_rms,    # (samples) -> counts
    compute_axis_statistics,        # (samples) -> per-axis means + RMS
    compute_acceleration_metrics,   # (samples, baseline) -> both metrics + axes
    compute_baseline_magnitude,     # (quiet samples) -> mean |a|
    counts_to_ms2,                  # the single unit conversion
    get_metric_value,               # (result_row, metric_name, unit) -> float|None
    save_raw_acceleration_samples,  # write the raw NPZ
    load_raw_acceleration_samples,  # read it back
    recompute_window_metrics,       # raw NPZ -> both metrics per window
    RawSampleRecorder,              # what the experiments record into
)
```

Spectral analysis (used by the adhesion comparison) lives here too, so a
second experiment can never grow a second, subtly different FFT:

```python
from validation_experiments.acceleration_metrics import (
    compute_vibration_spectrum,     # demeaned, Hann-windowed, 3-axis quadrature
    harmonic_amplitudes,            # fundamental + harmonics of a drive tone
    total_harmonic_distortion,      # sqrt(sum A_k^2, k>=2) / A_1, or None
)
```

Tone amplitudes are estimated from the main-lobe energy / ENBW (not the
single peak bin), so they do not depend on where the tone falls between
bin centres; a frequency the spectrum cannot measure returns `None`,
never a zero.

`samples` is a sequence of `(x, y, z)` or `(t, x, y, z)` tuples (the form
`rig.collect_samples()` returns) or an `(N, 3)` / `(N, 4)` array — all
accepted interchangeably.

`get_metric_value()` returns **`None`**, never a guess, when a row does
not carry the requested metric. It reads the pre-refactor column names
(`rms_delta`, `rms_delta_counts`, `rms_ms2`, `baseline_mag`, …) for the
legacy metric only: **a stored scalar magnitude RMS cannot be turned
back into a vector RMS**, and nothing in the codebase pretends
otherwise.

```python
from validation_experiments.report import (
    header,          # the "===== ... =====" block a report opens with
    stats_line,      # one aligned "mean / median / SD / range (n)" line
    table,           # a fixed-width text table
    number,          # a table cell, or "-" when the value is missing
    run_time_text,   # a run's saved time, from its meta / name / mtime
    stamp_from_path, # the epoch stamp in "<prefix>_<epoch>.csv"
)
```

Unit tests: `test-script/test_acceleration_metrics.py` and
`test-script/test_validation_reports.py` (run from `main/`, e.g.
`python test-script/test_acceleration_metrics.py`).

---

## 3. Summary-CSV columns

Each experiment's summary CSV keeps its own identity columns
(`freq_hz`/`amp`, `frequency_hz`/`sweep_pass`, `trial_id`/`status`/…)
and then carries this **identical block**, in this order:

| Column | Meaning |
|---|---|
| `n_samples` | samples in the measurement window |
| `mean_x_counts`, `mean_y_counts`, `mean_z_counts` | per-axis means (the static component the vector RMS removes) |
| `rms_x_counts`, `rms_y_counts`, `rms_z_counts` | per-axis demeaned RMS |
| `legacy_magnitude_rms_counts` | metric 1, raw counts |
| `legacy_magnitude_rms_ms2` | metric 1, m/s² |
| `vector_rms_counts` | metric 2, raw counts |
| `vector_rms_ms2` | metric 2, m/s² |
| `baseline_magnitude_counts` | quiet-window mean `|a|` metric 1 subtracted |
| `peak_magnitude_delta_counts` | largest single-sample `|a|` deviation (legacy secondary metric) |

`vector_rms_counts² = rms_x_counts² + rms_y_counts² + rms_z_counts²`, so
the axis breakdown and the headline metric are consistent by
construction.

---

## 4. Raw three-axis data

Every run writes `<summary_csv_stem>.raw_acc.npz` next to its CSV — a
**compressed NPZ in long format, one row per accelerometer sample**:

| Array | Meaning |
|---|---|
| `window_id` | unique id of the measurement window |
| `cell_id` | sweep cell / trial the window belongs to (−1 = none) |
| `trial_id` | repetition within the cell (−1 when unused) |
| `baseline_window_id` | which baseline window this window's legacy baseline came from (−1 = none) |
| `sweep_pass` | `""`, `"coarse"`, `"fine"` (stored as codes + a label table) |
| `phase` | `"baseline"` or `"vibration"` (same encoding) |
| `commanded_freq_hz`, `commanded_amp` | what the rig was told to do |
| `sensor_id` | LIS3DH sensor id in the `ACC` stream |
| `timestamp_s` | **Unix epoch seconds** (host arrival time) |
| `x`, `y`, `z` | raw LIS3DH counts, `int32` — lossless |
| `meta_json` | run id, experiment, `ms2_per_count`, `metric_version`, column list, plus the experiment's own parameters |

Baseline windows are stored too, and each vibration window records the
baseline window it used, so the **legacy metric can be reproduced with
the very baseline the live run subtracted** — not an approximation of it.

`recompute_window_metrics(raw)` turns the file straight back into both
metrics per window. On a real run this reproduces the summary CSV
exactly (verified to 0 counts of difference in the end-to-end check).

**Size.** Roughly 30 kB per 5 000 samples. A Coarse spectrogram run is a
few MB; a Fine, long-Vibrate-time 2-D sweep can reach tens of MB. The
sample count and file are printed at the end of every run.

---

## 5. Metadata block

Each run's `.meta.json` carries, alongside its own `parameters`:

```jsonc
"metrics": {
  "metric_version": 2,
  "available_metrics": ["vector_rms", "legacy_magnitude_rms"],
  "selected_plot_metric": "vector_rms",
  "default_plot_metric": "vector_rms",
  "raw_acceleration_file": "spectrogram_<ts>.raw_acc.npz",
  "raw_data_format": "acceleration_raw_npz_v1",
  "ms2_per_count": 0.00980665,
  "metric_definitions": { "...": "the formulas, in words" }
},
"files": { "...": "...", "raw_acceleration": "spectrogram_<ts>.raw_acc.npz" },
"result": { "metric": "vector_rms", "...": "always stated for the selected metric" }
```

`metric_version` is `1` for pre-refactor runs (single `rms_delta*`
column, no raw file) and `2` from this refactor onward.

Every run also carries a `haptic_config` block: the project's haptic
configuration (`config.json`'s `haptic`, via `common/haptic_config.py`)
as it stood when the run started, plus the actuator/motor-port map. For
the experiments that DRIVE at a single configured point (Motor → ACC
Delay, and the amplitude sweep's fixed frequency) it also records
whether the delivered value was the configured default or a manual
override (`amp_source`, `pwm_freq_source`, `freq_source`,
`motor_index_source` — `"config_default"` or `"manual"`).

`parameters` always records **what was actually sent to the rig**;
`haptic_config` only records the configuration it was compared against.
Re-rendering a saved run uses that run's own `parameters`, never the
current config — see main/README.md, "Haptic actuator configuration".

---

## 5.4 Reading a saved run as numbers

A chart cannot be read back as figures, so every experiment module also
exposes

```python
summary_report(csv_path, summary=None) -> list[str]
```

which rebuilds the run's console-style statistics from its saved CSV (+
its `.meta.json`): the parameters it ran with, a per-trial / per-step /
per-cell table, and the headline result — the same wording and the same
column alignment the live run prints, e.g.

```
Vibration onset latency:     mean     6.14 ms, median     5.88 ms, SD    1.20 ms, range 4.11-7.96 ms (n=10)
Settling time from onset:    mean   121.45 ms, median   120.55 ms, SD   11.52 ms, range 101.05-141.04 ms (n=10)
```

The shared line/table/header formatting lives in `report.py`. Every
metric-dependent figure is derived for the metric the displayed chart is
using, so the text and the picture can never describe different numbers;
switching the "Plot metric" selector reprints the block.

The GUI prints this into its log panel when a window opens on the latest
run, when a run is loaded, and on demand via **Show Statistics**. The
saved files themselves are never modified — the report is derived, not
stored.

### Picking a saved run

Each validation window lists the runs it finds in its own output folder
(newest first, with each run's time, file name and distinguishing
parameters) in a **Saved runs** picker; the list re-scans the folder each
time it is opened, so a command-line run appears without reopening the
window. **Browse...** still loads a CSV from anywhere on disk, and such a
file is shown in the list marked "(outside this folder)". A "saved ..."
figure in an entry is the headline result stored *with* that run, under
the metric it was saved with.

---

## 5.5 Reading the chart full size

The chart inside each experiment window is a **thumbnail** — a
four-panel latency summary or a spectrogram is unreadable at that size.
**Click the chart** (or press **Enlarge Chart**) to open it at its own
resolution in a separate viewer:

| Control | Action |
|---|---|
| **Fit to window** / `Ctrl+0` | scale to the window (never past 100 %) |
| **100 %** / `Ctrl+1` | the PNG's own resolution |
| **+** / **−**, `Ctrl+±`, `Ctrl+scroll` | zoom; scrollbars pan once the chart is larger than the window |
| `Esc` | close |

**One viewer is shared by all four experiment windows** — clicking a
chart in another window swaps the image rather than opening a second
viewer. It tracks the panel it was opened from, so finishing a run or
switching the Plot metric refreshes it in place (keeping your zoom), and
it closes automatically with the last validation window.

---

## 6. Picking the metric in the GUI

Launcher → **10. Validation Experiments** → any of the three intensity
windows has a **Plot metric** dropdown:

* **Demeaned 3-axis vector RMS (Recommended)** — the default
* **Legacy magnitude RMS**

Both metrics are measured every run, so switching the dropdown re-plots
the displayed run immediately — **no new hardware run**. The choice
drives the chart, the peak / resonance / recommended cue amp, the
in-cell annotations, the colour-bar or y-axis label, the run log's
strongest/peak lines, the `result` block of the meta and the GUI status
line.

**Metric-specific thresholds switch with it.** The two metrics are
different rulers — the legacy formula is only second-order sensitive to
vibration perpendicular to gravity, so on the same drive it reads
≈ 0.5 m/s² where the vector RMS reads ≈ 2.7 m/s². Any absolute
threshold therefore belongs to *one* metric. The amplitude sweep's
target cue band is defined per metric in `CUE_TARGETS` /
`cue_target(metric)` (see
[`lra_resonance_intensity_calibration/README.md`](lra_resonance_intensity_calibration/README.md)
§ 2.5); a metric with no calibrated band is reported as
`Target band not calibrated` and gets no recommendation rather than
borrowing the other's numbers.

**Old runs.** A run saved before raw three-axis samples were kept offers
the legacy metric only; the vector option is **disabled** with a
tooltip and the status line explains why, rather than the value being
faked. Starting a new run re-arms the dropdown with your own choice
(default: vector RMS), so previewing an old run never silently changes
what the next run measures.

The **Motor → ACC Delay** window has no such dropdown: its figure is a
latency plot, and its onset detector is deliberately untouched — see
§ 7.

---

## 7. What was NOT unified, and why

The motor→ACC delay experiment shares the raw-sample store, the shared
computation helpers and both offline intensity metrics per trial, but
its **onset/settling detector keeps its own statistic**: the per-sample
per-axis deviation from the per-trial baseline means, feeding a CUSUM
change-point test for the onset and a short centred moving RMS of the
same quantity — the vibration envelope — for the settling time.

The reason is that the two answer different questions. An RMS is an
average over a whole window and cannot *date* an event; onset detection
needs a per-sample quantity that responds within one sample. The three
are consistent by construction — the demeaned vector RMS is exactly the
RMS of that per-axis deviation over a window, i.e. the detector is the
per-sample form, the settling envelope the sliding-window form and the
metric the whole-window form — so nothing is gained by swapping one in,
while every historical latency number would change.

The per-trial intensity numbers that experiment records are **offline
only** and are never fed back into detection. They span the whole drive
window — quiet pre-onset samples, ring-up and steady state — so they
are *not* steady-state intensities comparable with a sweep cell; that
experiment's `steady_state_envelope_counts` is the settled level, and
the meta says so in its `drive_window_intensity` block.

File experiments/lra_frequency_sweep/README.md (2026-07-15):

# LRA Resonance and Intensity Calibration

Two linked calibration experiments that determine the **optimal drive
configuration of the LRA** used by the haptic-piano system:

1. **Frequency sweep** (`lra_frequency_sweep.py`) — find the mounted
   resonant frequency f₀, the frequency at which the LRA vibrates the
   strongest.
2. **Amplitude sweep** (`lra_amplitude_sweep.py`) — at f₀, find the PWM
   amplitude (`amp`) whose measured acceleration lands in the target
   "clearly perceptible, not annoying" band.

Outcome adopted by the project: **f₀ = 224 Hz** (firmware boot default
since v2.7.0) and **`amp = 64`** (default intensity in all Python
code). Every later experiment that delivers haptic cues rests on these
two constants, which is why the calibration is documented in full
below.

---

## 1. Introduction

An LRA (linear resonant actuator) is a spring–mass resonator: it only
produces strong vibration when driven with an AC signal at its resonant
frequency f₀, and its response falls off steeply within a few Hz of the
peak (high Q). Two facts make a one-off calibration necessary:

- **The datasheet f₀ is only nominal.** The resonance of the *mounted*
  actuator shifts by several Hz with the attachment method, the mass it
  drives, and temperature, so f₀ must be measured on the assembled rig.
- **Drive strength is nonlinear in the PWM duty.** With this rig's
  unipolar (single-transistor) drive on a 10 V rail, the LRA responds
  to the AC fundamental of the PWM square wave, whose amplitude is
  proportional to `sin(π·amp/255)` — it peaks at `amp = 128` and falls
  back to zero at 255. `amp` values are therefore only meaningful in
  the monotonic 0–128 range, and the mapping from `amp` to perceived
  strength has to be measured, not assumed.

The calibration answers two questions: *at what frequency should the
LRA be driven* (Experiment 1), and *at what amplitude, given that
frequency, is the cue clearly perceptible without being unpleasantly
strong* (Experiment 2). Getting both right matters for every later
user study: an off-resonance drive wastes most of the actuator's output
and confounds intensity comparisons, and an over-strong default was in
fact reported as subjectively uncomfortable during piloting.

## 2. Method

### 2.1 Apparatus

| Item | Value |
|---|---|
| Actuator | Coin LRA, wired to motor **port 0**, stuck to the desk with Blu-Tack (adhesive putty) |
| Sensor | LIS3DH accelerometer, sensor 0 (CS pin 36), coupled to the LRA through the same Blu-Tack mount; ±2 g high-resolution mode (1 count = 1 mg) |
| Drive | Teensy 4.1 PWM through the motor driver board, 10 V motor rail; `haptic-piano` firmware **v2.6.0+** (`F` frequency command, `ACC,id,x,y,z` stream) |
| Sampling | `A START 3` (3 ms interval; the LIS3DH ODR is 400 Hz) |

The rig sits untouched on the desk for the whole run — hand-holding it
adds motion noise to both the baseline and the vibration windows.

### 2.2 Experiment 1 — frequency sweep

Amplitude fixed at `amp = 128` (the maximum AC fundamental, so the
resonance peak has the best signal-to-noise ratio). Two passes:

1. **Coarse**: 100 → 350 Hz in 5 Hz steps.
2. **Fine**: coarse peak ±10 Hz in 1 Hz steps.

Each frequency step runs: set frequency (`F 0 <freq>`) → record a
0.30 s quiet baseline → motor on (`S 1 128`) → 0.15 s settling (LRA
ring-up) → 0.40 s measurement → motor off → 0.15 s rest. The baseline
is re-measured at every step so slow drift cannot bias the curve.
Total duration ≈ 1.5 min.

### 2.3 Experiment 2 — amplitude sweep

Frequency fixed at the Experiment 1 result (224 Hz); `amp` stepped
4 → 128 in steps of 4 with the same per-step protocol (~35 s total).

### 2.4 Measures

The per-step metric is the **RMS delta**: the root-mean-square of
`|a| − baseline_mean` over the measurement window, in raw LIS3DH
counts. For Experiment 2 it is converted to absolute units via the
sensor's high-resolution sensitivity, 1 count = 1 mg:
`a[m/s²] = counts × 0.00981`. `peak_delta` (largest single-sample
deviation) is logged as a secondary metric.

### 2.5 Standards and choice of the target band

No standard prescribes a haptic-cue intensity, so the target band is
perception-based, with the relevant standards used to scope the
problem:

- **ISO 2631-1 (whole-body vibration)** is *not applicable*: its
  frequency weightings stop at 80 Hz, below the 224 Hz drive. Its
  comfort descriptor scale (< 0.315 m/s² "not uncomfortable") is used
  only as a conservative order-of-magnitude cross-check.
- **ISO 5349-1 (hand-transmitted vibration, 8–1000 Hz)** *covers* the
  frequency range but regulates occupational *exposure*: the daily
  action value is A(8) = 2.5 m/s² (Wh-weighted, 8 h). Short haptic
  cues at < 1 m/s² unweighted are orders of magnitude below it —
  safety is therefore not the binding constraint, comfort and
  detectability are.
- **Psychophysics** sets the actual target: fingertip vibrotactile
  detection thresholds near 200–250 Hz (the Pacinian corpuscle
  sensitivity peak) are ~0.1–0.4 m/s² RMS, and a clearly perceptible
  but non-annoying cue is conventionally placed just above threshold.

Target band adopted: **0.4–0.6 m/s² RMS**, aiming at its centre
(0.5 m/s²).

### 2.6 Running the experiments

```bash
python lra_frequency_sweep.py    # ~1.5 min, prints f0
python lra_amplitude_sweep.py    # ~35 s, prints recommended amp
```

Both scripts auto-detect the rig (USB VID:PID `16C0:0483`, confirmed by
the `E` → `E haptic-piano ...` handshake), and on exit — including
Ctrl+C — stop all motors, restore the boot-default frequency and stop
the accelerometer stream. Outputs are timestamped into `output/`:

| File | Content |
|---|---|
| `sweep_<ts>.csv` / `frequency_response_<ts>.png` | Experiment 1 data and plot |
| `amp_sweep_<ts>.csv` / `amplitude_response_<ts>.png` | Experiment 2 data and plot |

## 3. Results (runs of 2026-07-15)

### 3.1 Experiment 1 — resonant frequency

Data `output/sweep_20260715_152236.csv`, plot
`output/frequency_response_20260715_152236.png`.

- **f₀ = 224 Hz** (fine-pass peak: `rms_delta = 111.1` counts,
  `peak_delta = 298` counts).
- The resonance region spans ~221–231 Hz (`rms_delta ≈ 103–111`), with
  the sharp high-side cliff typical of a high-Q resonator (231 → 232 Hz
  drops from 105 to 67).
- At the previous 300 Hz default the same drive produced
  `rms_delta ≈ 40`: retuning to 224 Hz yields **~2.8× more vibration**
  from the same voltage.

### 3.2 Experiment 2 — amplitude at 224 Hz

Data `output/amp_sweep_20260715_153925.csv`, plot
`output/amplitude_response_20260715_153925.png`.

- **Recommended `amp = 64`** → 0.49 m/s² RMS, the centre of the target
  band. In-band alternatives: `amp = 60` (0.40) and `amp = 68` (0.57).
- The interim default `amp = 75` measures ≈ 0.65 m/s² — above the
  band, consistent with pilot feedback that it felt too strong.
- Below `amp ≈ 56` readings flatten at ~0.28–0.38 m/s²: this is the
  rig's measurement noise floor (baseline |a| jitter), not real
  vibration; absolute values below ~0.4 m/s² are not trustworthy.
- From `amp ≈ 60` upward the curve tracks the `sin(π·amp/255)` model
  well; above `amp ≈ 88` it plateaus at 0.72–0.84 m/s² (LRA stroke
  saturation) rather than following the model to its 128 peak.

## 4. Discussion

### 4.1 Adopted configuration

| Setting | Value | Where it lives |
|---|---|---|
| LRA drive frequency | **224 Hz** | firmware boot default (`DEFAULT_PWM_FREQ`, since v2.7.0); can be overridden at runtime with `F <port> <freq>` |
| Default cue intensity | **`amp = 64`** (0.49 m/s² RMS at 224 Hz) | `HAPTIC_AMPLITUDE` in `app/haptic_cue.py`, `pulse()` defaults in `common/controller.py`, and the `AMP` constants of the experiment scripts |

### 4.2 Interpretation

- The measured amplitude curve validates the `sin(π·amp/255)` drive
  model in the usable region and reveals stroke saturation above
  `amp ≈ 88` — driving harder than ~90 gains nothing, which bounds the
  useful intensity range to roughly 60–90.
- The division of labour confirmed by these data: **frequency is a
  calibration constant** (set once to f₀, never used as an intensity
  knob — the resonance is only ~10 Hz wide and detuning changes the
  perceived pitch as well as the strength), while **intensity is
  controlled by `amp`** within the monotonic, unsaturated 0–90 region.

### 4.3 Limitations

- f₀ is **mount-specific**: 224 Hz holds for this Blu-Tack desk mount.
  Re-run Experiment 1 (and ideally Experiment 2) whenever the LRA is
  remounted, e.g. onto the finger rig — expect a shift of a few Hz.
- Absolute intensities below ~0.4 m/s² are floor-limited on this rig;
  a stiffer mount or averaging longer windows would be needed to
  resolve them.
- Single actuator, single session: unit-to-unit spread and temperature
  drift are not characterised (both are typically a few Hz for coin
  LRAs — within the measured 221–231 Hz plateau).
- The 0.4–0.6 m/s² band is a design target from perception literature,
  not a standard's requirement; per-user preference can still be
  exposed as a setting (60/64/68 are all in-band).

### 4.4 Troubleshooting a re-run

- A flat frequency curve with no peak usually means the accelerometer
  is not mechanically coupled to the LRA (check the Blu-Tack) or the
  motor is not on port 0 (`MOTOR_INDEX`).
- A peak at the edge of the sweep range: widen `COARSE_START_HZ` /
  `COARSE_STOP_HZ`.
- `amp = 128` on the 10 V rail is a deliberate short-burst overdrive
  (0.4 s bursts are fine; haptic driver ICs overdrive on purpose for
  fast ring-up) — avoid holding the LRA at high `amp` continuously.

## Appendix: configuration constants

All knobs are constants at the top of each script:

| Constant | Default | Meaning |
|---|---|---|
| `MOTOR_INDEX` | 0 | motor port driving the LRA |
| `AMP` (Exp 1) | 128 | sweep drive amplitude (max AC fundamental) |
| `FREQ_HZ` (Exp 2) | 224 | fixed drive frequency for the amplitude sweep |
| `AMP_VALUES` (Exp 2) | 4–128 step 4 | amplitude steps |
| `TARGET_BAND_MS2` / `TARGET_MS2` (Exp 2) | 0.4–0.6 / 0.5 | target cue band and aim point |
| `COARSE_START_HZ` / `COARSE_STOP_HZ` / `COARSE_STEP_HZ` (Exp 1) | 100 / 350 / 5 | coarse pass range and step |
| `FINE_SPAN_HZ` / `FINE_STEP_HZ` (Exp 1) | 10 / 1 | fine pass around the coarse peak |
| `BASELINE_S` / `SETTLE_S` / `MEASURE_S` / `REST_S` | 0.30 / 0.15 / 0.40 / 0.15 | per-step timing |
| `ACC_INTERVAL_MS` | 3 | stream interval (LIS3DH ODR is 400 Hz, keep ≥ 3) |
| `MS2_PER_COUNT` (Exp 2) | 0.00981 | LIS3DH HR ±2 g: 1 count = 1 mg |

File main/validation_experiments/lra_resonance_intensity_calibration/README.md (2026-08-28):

# LRA Resonance and Intensity Calibration

Two linked calibration experiments that determine the **optimal drive
configuration of the LRA** used by the haptic-piano system:

1. **Frequency sweep** (`lra_frequency_sweep.py`) — find the mounted
   resonant frequency f₀, the frequency at which the LRA vibrates the
   strongest.
2. **Amplitude sweep** (`lra_amplitude_sweep.py`) — at f₀, find the
   **recommended cue amp**: the PWM amplitude (`amp`) whose measured
   acceleration is *closest to the target "clearly perceptible, not
   annoying" intensity*. Note what this is **not** — it is not the amp
   that produces the strongest vibration (that is just the top of the
   sweep range) and not a physically optimal operating point of the
   actuator. It is the amp nearest a chosen target intensity, and the
   target is defined **per metric** (§ 2.5).

Outcome adopted by the project: **f₀ = 224 Hz** (firmware boot default
since v2.7.0) and **`amp = 64`** (default intensity in all Python
code). Every later experiment that delivers haptic cues rests on these
two constants, which is why the calibration is documented in full
below.

---

## 1. Introduction

An LRA (linear resonant actuator) is a spring–mass resonator: it only
produces strong vibration when driven with an AC signal at its resonant
frequency f₀, and its response falls off steeply within a few Hz of the
peak (high Q). Two facts make a one-off calibration necessary:

- **The datasheet f₀ is only nominal.** The resonance of the *mounted*
  actuator shifts by several Hz with the attachment method, the mass it
  drives, and temperature, so f₀ must be measured on the assembled rig.
- **Drive strength is nonlinear in the PWM duty.** With this rig's
  unipolar (single-transistor) drive on a 9 V rail, the LRA responds
  to the AC fundamental of the PWM square wave, whose amplitude is
  proportional to `sin(π·amp/255)` — it peaks at `amp = 128` and falls
  back to zero at 255. `amp` values are therefore only meaningful in
  the monotonic 0–128 range, and the mapping from `amp` to perceived
  strength has to be measured, not assumed.

The calibration answers two questions: *at what frequency should the
LRA be driven* (Experiment 1), and *at what amplitude, given that
frequency, is the cue clearly perceptible without being unpleasantly
strong* (Experiment 2). Getting both right matters for every later
user study: an off-resonance drive wastes most of the actuator's output
and confounds intensity comparisons, and an over-strong default was in
fact reported as subjectively uncomfortable during piloting.

## 2. Method

### 2.1 Apparatus

| Item | Value |
|---|---|
| Actuator | Coin LRA, wired to motor **port 11**, stuck to the desk with Blu-Tack (adhesive putty) |
| Sensor | LIS3DH accelerometer, sensor 0 (CS pin 36), coupled to the LRA through the same Blu-Tack mount; ±2 g high-resolution mode (1 count = 1 mg) |
| Drive | Teensy 4.1 PWM through the motor driver board, 9 V motor rail; `haptic-piano` firmware **v2.6.0+** (`F` frequency command, `ACC,id,x,y,z` stream) |
| Sampling | `A START 3` (3 ms interval; the LIS3DH ODR is 400 Hz) |

The rig sits untouched on the desk for the whole run — hand-holding it
adds motion noise to both the baseline and the vibration windows.

### 2.2 Experiment 1 — frequency sweep

Amplitude fixed at `amp = 128` (the maximum AC fundamental, so the
resonance peak has the best signal-to-noise ratio). Two passes:

1. **Coarse**: 100 → 350 Hz in 5 Hz steps.
2. **Fine**: coarse peak ±10 Hz in 1 Hz steps.

Each frequency step runs: set frequency (`F 0 <freq>`) → record a
0.30 s quiet baseline → motor on (`S 1 128`) → 0.15 s settling (LRA
ring-up) → 0.40 s measurement → motor off → 0.15 s rest. The baseline
is re-measured at every step so slow drift cannot bias the curve.
Total duration ≈ 1.5 min.

### 2.3 Experiment 2 — amplitude sweep

Frequency fixed at the Experiment 1 result (224 Hz); `amp` stepped
4 → 128 in steps of 4 with the same per-step protocol (~35 s total).

### 2.4 Measures

Every measurement window is scored with **both** shared
vibration-intensity metrics (defined in full in
[`../README.md`](../README.md) § 1, implemented once in
`../acceleration_metrics.py`):

| Metric | Formula (raw LIS3DH counts) | Role |
|---|---|---|
| `vector_rms` — **demeaned 3-axis vector RMS** | `√(mean((x−x̄)² + (y−ȳ)² + (z−z̄)²))`, equivalently `√(rms_x² + rms_y² + rms_z²)` | **the default.** Each axis is demeaned over the window, so gravity, the sensor's static bias and the mounting pose drop out |
| `legacy_magnitude_rms` — **legacy magnitude RMS** | `√(mean((\|a\|ᵢ − baseline_magnitude)²))` | the original formula (§ 3's historical numbers are in these units), kept for like-for-like comparison with earlier runs |

`baseline_magnitude` is the mean `|a|` of the quiet window re-measured
at every step. Both metrics are converted to absolute units **once**,
via the sensor's high-resolution sensitivity (1 count = 1 mg):
`a[m/s²] = counts × 0.00980665`; every stored field name carries a
`_counts` or `_ms2` suffix. `peak_magnitude_delta_counts` (largest
single-sample `|a|` deviation) is logged as a legacy secondary metric,
and the per-axis means and RMS values are stored too.

Which metric is **plotted** — and therefore which frequency is reported
as f₀ and which amp is the recommended cue amp — is chosen with the
**Plot metric** dropdown (default: vector RMS). It is a plot-time
choice: both metrics and the full raw three-axis samples are saved, so a
run can be re-analysed under either without re-running the hardware. The
legacy metric is only second-order sensitive to vibration perpendicular
to gravity, so on a rig whose LRA does not push along gravity the two
can give different answers; the run log prints the other metric's peak
so the difference is visible.

**The two metrics are different rulers, so each has its OWN target
band** — see § 2.5. Switching the Plot metric switches the curve, the
shaded band, the target value, the recommended cue amp, the in-band
list, the legend, the title, the meta `result` block and the GUI status
line *together*.

### 2.5 Target cue intensity — one band **per metric**

The amplitude sweep does not look for the strongest vibration; it looks
for the amp closest to a **target cue intensity**. That target is a
number in m/s², so it only means anything alongside the metric that
measures it — and **the two metrics are different rulers**. On this rig
the same drive reads ≈ 0.5 m/s² under the legacy magnitude RMS and
≈ 2.7 m/s² under the demeaned vector RMS, because the legacy formula is
only second-order sensitive to vibration perpendicular to gravity while
the vector RMS captures the full AC energy.

> **This used to be a bug.** Both metrics shared the legacy
> 0.4–0.6 m/s² band, so switching the Plot metric moved the recommended
> amp from ≈ 52 to ≈ 4. That looked like a change in the actuator's
> operating point but was only a change of ruler. Each metric now has
> its own band and both select amp ≈ 52 on the same data.

| Metric | Target band | Aim point | Calibration |
|---|---|---|---|
| Legacy magnitude RMS | **0.4–0.6 m/s²** | 0.5 m/s² | `historical` — the perception-based band the project adopted `amp = 64` from |
| Demeaned 3-axis vector RMS | **2.4–3.0 m/s²** | 2.7 m/s² | `provisional` — estimated from the vector RMS this rig measured at amp ≈ 48–56 (2.55–2.94 m/s²) |

The vector band is **provisional**: it is a rescaling of the historical
band onto this metric's scale — the same physical drive range, measured
with the better ruler — *not* an independent perceptual calibration.
Expect it to be re-measured; every run's meta records the status so a
saved result always states how firm its target was.

All of these live in **one place**, `CUE_TARGETS` /
`cue_target(metric)` in `lra_amplitude_sweep.py`. Nothing else — not the
plot, not the recommendation, not the GUI — may hard-code a band.

**Uncalibrated metrics.** `cue_target()` returns an *uncalibrated*
target for any metric with no entry. Such a metric gets its curve
plotted and nothing else: the plot and the meta say
`Target band not calibrated`, no cue amp is recommended and the in-band
list is empty. Another metric's thresholds are never substituted.

#### Where the numbers come from

No standard prescribes a haptic-cue intensity, so the target band is
perception-based, with the relevant standards used to scope the
problem:

- **ISO 2631-1 (whole-body vibration)** is *not applicable*: its
  frequency weightings stop at 80 Hz, below the 224 Hz drive. Its
  comfort descriptor scale (< 0.315 m/s² "not uncomfortable") is used
  only as a conservative order-of-magnitude cross-check.
- **ISO 5349-1 (hand-transmitted vibration, 8–1000 Hz)** *covers* the
  frequency range but regulates occupational *exposure*: the daily
  action value is A(8) = 2.5 m/s² (Wh-weighted, 8 h). Short haptic
  cues at < 1 m/s² unweighted are orders of magnitude below it —
  safety is therefore not the binding constraint, comfort and
  detectability are.
- **Psychophysics** sets the actual target: fingertip vibrotactile
  detection thresholds near 200–250 Hz (the Pacinian corpuscle
  sensitivity peak) are ~0.1–0.4 m/s² RMS, and a clearly perceptible
  but non-annoying cue is conventionally placed just above threshold.

Target band adopted for the **legacy magnitude RMS**:
**0.4–0.6 m/s² RMS**, aiming at its centre (0.5 m/s²). The vector-RMS
band above is that same drive range re-expressed on the vector scale.
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

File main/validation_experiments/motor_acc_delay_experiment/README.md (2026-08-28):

# Motor → Accelerometer Delay and Settling

Measures, per trial, **how long the actuator takes to start moving and
how long it then takes to reach a steady vibration** after the host
issues a motor-on command, for both actuator types on the rig (LRA and
ERM). This is the electromechanical part of the haptic-cue latency
chain, and the validation behind treating the haptic command timestamp
as the cue-onset time in the main user study's reaction-time logging.

## 1. What is measured

```
host t_cmd ── "S mask amp" ──USB──> firmware ──PWM──> motor starts moving
                                                          │ mechanical coupling
host records x,y,z  <──USB── "ACC,id,x,y,z" @1 kHz <── LIS3DH glued to the motor
                                     (for the whole Vibration duration)
```

### The three instants, and the two latencies derived from them

Every trial records **three times**, all stored as Unix epoch seconds:

| Column | Meaning |
|---|---|
| `command_time_s` | the host clock at the `S` motor-on write |
| `onset_time_s` | the first sustained departure from the rest noise |
| `stable_time_s` | the first instant the envelope enters the steady band **and holds it** |

and derives from them:

```
onset_latency_from_command  = onset_time  − command_time
settling_time_from_onset    = stable_time − onset_time
stable_latency_from_command = stable_time − command_time
```

**Onset latency and settling time are separate metrics** and are never
merged, summed or averaged into a single "delay"; the summary reports
mean/median/SD/range for each independently. Because "settling time"
is ambiguous about which zero it is measured from, **both forms are
stored**: `settling_time_from_onset_ms` and
`stable_latency_from_command_ms`.

- **Vibration onset latency** (`onset_ms`, also written as
  `onset_latency_from_command_ms`) — the command-to-first-motion
  latency: serial write + firmware dispatch + motor start-up +
  mechanical transmission + sensor sampling + return trip. It marks
  the point where the signal *leaves the rest noise and starts rising*
  — not where it peaks and not where it stabilises.
- **Settling time** (`settling_time_from_onset_ms`) — the rise: how
  long the vibration takes from that onset to a steady, sustained
  amplitude.

A third, historical metric is still reported alongside them:
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

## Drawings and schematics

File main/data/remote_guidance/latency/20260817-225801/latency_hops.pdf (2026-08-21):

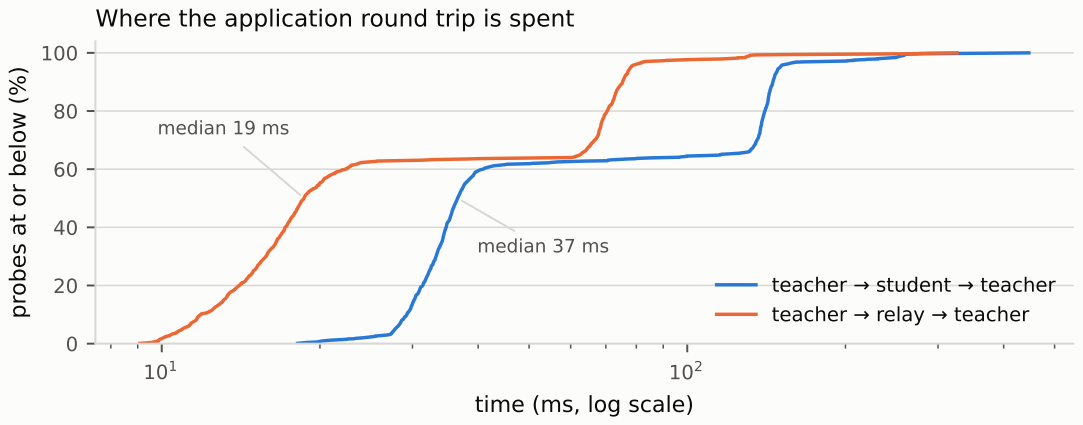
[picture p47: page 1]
median 37 ms; median 19 ms

Where the application round trip is spent

probes at or below (%)

teacher → student → teacher
teacher → relay → teacher

time (ms, log scale)

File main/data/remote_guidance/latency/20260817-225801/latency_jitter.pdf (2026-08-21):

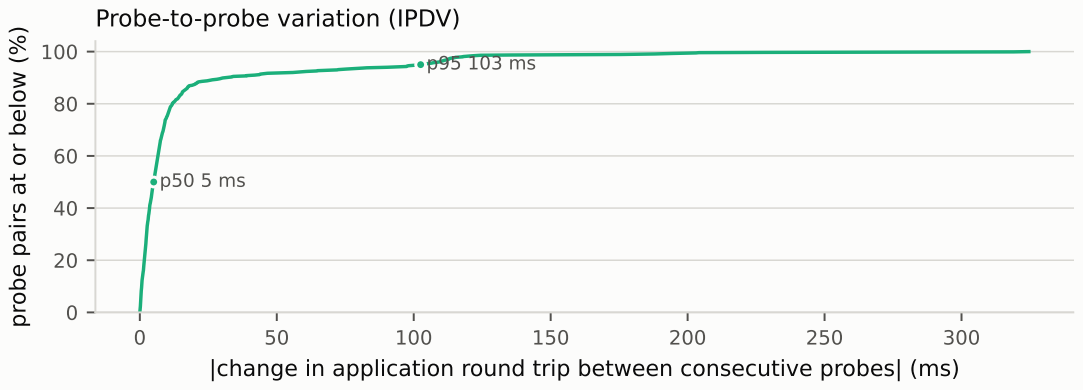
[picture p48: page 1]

Probe-to-probe variation (IPDV)
change in application round trip between consecutive probes| (ms)

probe pairs at or below (%)

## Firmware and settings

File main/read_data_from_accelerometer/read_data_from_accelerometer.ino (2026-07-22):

const int PIN_CS   = 36;
const int PIN_SCK  = 33;
const int PIN_MOSI = 34;
const int PIN_MISO = 35;

void spiDelay() {
  delayMicroseconds(3);
}

// SPI MODE3
uint8_t spiTransfer(uint8_t data) {
  uint8_t rx = 0;

  for (int i = 7; i >= 0; i--) {

    digitalWrite(PIN_SCK, HIGH);
    spiDelay();

    digitalWrite(PIN_MOSI, (data >> i) & 1);
    spiDelay();

    digitalWrite(PIN_SCK, LOW);
    spiDelay();

    rx <<= 1;
    if (digitalRead(PIN_MISO))
      rx |= 1;

    spiDelay();
  }

  digitalWrite(PIN_SCK, HIGH);
  return rx;
}

void writeReg(uint8_t reg, uint8_t val) {
  digitalWrite(PIN_CS, LOW);
  spiTransfer(reg & 0x7F);
  spiTransfer(val);
  digitalWrite(PIN_CS, HIGH);
}

uint8_t readReg(uint8_t reg) {
  digitalWrite(PIN_CS, LOW);
  spiTransfer(0x80 | reg);
  uint8_t v = spiTransfer(0x00);
  digitalWrite(PIN_CS, HIGH);
  return v;
}

void readAccel(int16_t &x, int16_t &y, int16_t &z) {

  digitalWrite(PIN_CS, LOW);

  spiTransfer(0xC0 | 0x28);   // read + auto increment

  uint8_t xL = spiTransfer(0);
  uint8_t xH = spiTransfer(0);
  uint8_t yL = spiTransfer(0);
  uint8_t yH = spiTransfer(0);
  uint8_t zL = spiTransfer(0);
  uint8_t zH = spiTransfer(0);

  digitalWrite(PIN_CS, HIGH);

  x = (int16_t)((xH << 8) | xL) >> 4;
  y = (int16_t)((yH << 8) | yL) >> 4;
  z = (int16_t)((zH << 8) | zL) >> 4;
}

void setup() {

  Serial.begin(115200);

  pinMode(PIN_CS, OUTPUT);
  pinMode(PIN_SCK, OUTPUT);
  pinMode(PIN_MOSI, OUTPUT);
  pinMode(PIN_MISO, INPUT);

  digitalWrite(PIN_CS, HIGH);
  digitalWrite(PIN_SCK, HIGH);

  delay(100);

  Serial.println("LIS3DH init");

  // 开启传感器
  writeReg(0x20, 0x77);   // 400Hz + XYZ enable
  writeReg(0x23, 0x88);   // High resolution

}

void loop() {

  int16_t x,y,z;

  readAccel(x,y,z);

  Serial.print(x);
  Serial.print(",");
  Serial.print(y);
  Serial.print(",");
  Serial.println(z);

  delay(10);
}

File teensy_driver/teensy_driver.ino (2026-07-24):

#include <Arduino.h>
#include "motor_driver.h"
#include "LED_array.h"
#include "accel_driver.h"

#define FW_NAME "haptic-piano"
#define FW_VERSION "v2.10.0"

// ===== serial buffer =====
static char lineBuf[128];
static uint8_t lineLen = 0;
static bool overflow = false;

// Skip spaces/tabs at the beginning
static char* skipSpaces(char* p) {
  while (*p == ' ' || *p == '\t') p++;
  return p;
}

// Read one full command line from Serial
static bool readLine() {
  while (Serial.available() > 0) {
    char c = (char)Serial.read();

    if (c == '\r') continue;

    if (c == '\n') {
      if (overflow) {
        overflow = false;
        lineLen = 0;
        return false;
      }
      lineBuf[lineLen] = '\0';
      lineLen = 0;
      return true;
    }

    if (lineLen < sizeof(lineBuf) - 1) {
      lineBuf[lineLen++] = c;
    } else {
      overflow = true;
    }
  }
  return false;
}

// Return firmware identity: "E <name> <version>". The device name makes
// the reply distinctive enough to double as a host-side auto-detect probe.
static void handleEcho() {
  Serial.print("E ");
  Serial.print(FW_NAME);
  Serial.print(' ');
  Serial.println(FW_VERSION);
}

void setup() {
  Serial.begin(115200);

  motorInit();
  ledInit();
  accelInit();
}

void loop() {
  // Check and dispatch any already-arrived command first, so it isn't
  // stuck behind the (potentially blocking) subsystem updates below.
  if (readLine()) {
    char* p = skipSpaces(lineBuf);

    if (*p) {
      char cmd = *p++;
      p = skipSpaces(p);

      // ===== motor =====
      if (cmd == 'X') {
        stopAll();
      } else if (cmd == 'E') {
        handleEcho();
      } else if (cmd == 'P') {
        handlePulse(p);
      } else if (cmd == 'S') {
        handleImmediate(p);

      // F idx freq (set PWM frequency on motor pin idx 0-11, -1 = all)
      } else if (cmd == 'F') {
        handleFrequency(p);

      // ===== accelerometer =====
      // A HELP | A WHOAMI | A READ | A START [interval_ms] | A STOP | A RATE interval_ms | A STATUS
      } else if (cmd == 'A') {
        handleAccelCommand(p);

      // ===== LED =====
      // L strip idx r g b brightness
      } else if (cmd == 'L') {
        handleLEDSet(p);

      // B brightness
      } else if (cmd == 'B') {
        handleLEDGlobalBrightness(p);

      // C strip (strip = 0 / 1 / -1(all))
      } else if (cmd == 'C') {
        handleLEDClear(p);

      // U (force LED output immediately)
      } else if (cmd == 'U') {
        handleLEDShowNow();
      }
    }
  }

  // Non-blocking updates (accel SPI read still briefly blocks, so these run
  // after command dispatch, not before it).
  updateMotors();
  updateLEDs();
  updateAccelerometer();
}

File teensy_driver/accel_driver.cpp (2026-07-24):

#include "accel_driver.h"

// Confirmed working bus mapping from brute-force search:
// SCK=33, MOSI=34, MISO=35 (shared), CS=36 (per sensor)
static const uint8_t PIN_SCK  = 33;
static const uint8_t PIN_MOSI = 34;
static const uint8_t PIN_MISO = 35;

// Chip-select pins, one per LIS3DH on the shared SPI bus. Sensor id =
// index in this array (36 -> id 0, 37 -> id 1, 38 -> id 2). All three
// slots are probed at boot / A WHOAMI / A START; absent sensors simply
// stay undetected and are skipped by streaming, so a sensor can be
// wired to any of these CS pins without re-flashing. To go beyond
// three, append another free GPIO here and re-flash.
static const uint8_t CS_PINS[] = {36, 37, 38};
static const uint8_t NUM_ACCEL = sizeof(CS_PINS) / sizeof(CS_PINS[0]);

// LIS3DH registers
static const uint8_t REG_WHO_AM_I   = 0x0F;
static const uint8_t REG_CTRL1      = 0x20;
static const uint8_t REG_CTRL4      = 0x23;
static const uint8_t REG_OUT_X_L    = 0x28;
static const uint8_t LIS3DH_ID      = 0x33;

struct AccelState {
  bool detected[NUM_ACCEL] = {};
  bool streamEnabled = false;
  uint32_t intervalMs = 10;
  uint32_t nextStreamMs = 0;
  uint32_t droppedFrames = 0;
};

static AccelState g_accel;

// Half-phase delay for the bit-banged bus. 100 ns per phase (~2.5 MHz
// clock) stays well inside the LIS3DH's 10 MHz SPI limit while leaving
// margin for jumper wiring. The old delayMicroseconds(3) here made one
// XYZ read block the main loop for ~0.8 ms.
static inline void spiDelayShort() {
  delayNanoseconds(100);
}

// Bit-banged SPI MODE3 (CPOL=1, CPHA=1)
static uint8_t spiTransfer(uint8_t data) {
  uint8_t rx = 0;

  for (int i = 7; i >= 0; --i) {
    digitalWriteFast(PIN_SCK, HIGH);
    spiDelayShort();

    digitalWriteFast(PIN_MOSI, (data >> i) & 0x01);
    spiDelayShort();

    digitalWriteFast(PIN_SCK, LOW);
    spiDelayShort();

    rx <<= 1;
    if (digitalReadFast(PIN_MISO)) {
      rx |= 1;
    }

    spiDelayShort();
  }

  digitalWriteFast(PIN_SCK, HIGH);
  spiDelayShort();
  return rx;
}

static void writeReg(uint8_t sensor, uint8_t reg, uint8_t value) {
  digitalWriteFast(CS_PINS[sensor], LOW);
  spiTransfer(reg & 0x7F);
  spiTransfer(value);
  digitalWriteFast(CS_PINS[sensor], HIGH);
}

static uint8_t readReg(uint8_t sensor, uint8_t reg) {
  digitalWriteFast(CS_PINS[sensor], LOW);
  spiTransfer(0x80 | reg);
  uint8_t value = spiTransfer(0x00);
  digitalWriteFast(CS_PINS[sensor], HIGH);
  return value;
}

static void readAccelRaw(uint8_t sensor, int16_t &x, int16_t &y, int16_t &z) {
  digitalWriteFast(CS_PINS[sensor], LOW);
  spiTransfer(0xC0 | REG_OUT_X_L); // read + auto-increment

  uint8_t xL = spiTransfer(0x00);
  uint8_t xH = spiTransfer(0x00);
  uint8_t yL = spiTransfer(0x00);
  uint8_t yH = spiTransfer(0x00);
  uint8_t zL = spiTransfer(0x00);
  uint8_t zH = spiTransfer(0x00);

  digitalWriteFast(CS_PINS[sensor], HIGH);

  x = (int16_t)((xH << 8) | xL) >> 4;
  y = (int16_t)((yH << 8) | yL) >> 4;
  z = (int16_t)((zH << 8) | zL) >> 4;
}

static bool canWriteLine(size_t n) {
  return Serial.availableForWrite() >= (int)n;
}

// Unified stream format "ACC,<id>,x,y,z" for every sensor, where <id> is
// the sensor's index in CS_PINS. Host-side parsers key on the id field.
static void printSampleLine(uint8_t sensor, int16_t x, int16_t y, int16_t z) {
  if (!canWriteLine(40)) {
    g_accel.droppedFrames++;
    return;
  }

  Serial.print("ACC,");
  Serial.print(sensor);
  Serial.print(',');
  Serial.print(x);
  Serial.print(',');
  Serial.print(y);
  Serial.print(',');
  Serial.println(z);
}

static uint8_t detectedCount() {
  uint8_t n = 0;
  for (uint8_t s = 0; s < NUM_ACCEL; s++) {
    if (g_accel.detected[s]) n++;
  }
  return n;
}

static void printStatusLine() {
  if (!canWriteLine(80)) return;

  Serial.print("ACC STATUS detected=");
  Serial.print(detectedCount());
  Serial.print('/');
  Serial.print(NUM_ACCEL);
  Serial.print(" stream=");
  Serial.print(g_accel.streamEnabled ? 1 : 0);
  Serial.print(" interval_ms=");
  Serial.print(g_accel.intervalMs);
  Serial.print(" dropped=");
  Serial.println(g_accel.droppedFrames);
}

static void configureLIS3DH(uint8_t sensor) {
  // 1.344 kHz data rate (HR/normal mode) + XYZ enable - raised from
  // 400 Hz (0x77) in v2.9.0 so the delay experiment can stream at 1 ms
  // without duplicate samples (~0.74 ms sensor period).
  writeReg(sensor, REG_CTRL1, 0x97);
  // High-resolution mode, +/-2g, BDU on (0x88 sets bit7: the X/Y/Z output
  // registers only update between reads, preventing high/low byte tearing)
  writeReg(sensor, REG_CTRL4, 0x88);
}

// Probe one sensor; (re)configure it if it answers.
static bool detectSensor(uint8_t sensor) {
  uint8_t whoami = readReg(sensor, REG_WHO_AM_I);
  g_accel.detected[sensor] = (whoami == LIS3DH_ID);
  if (g_accel.detected[sensor]) configureLIS3DH(sensor);
  return g_accel.detected[sensor];
}

// ===== Brute-force wiring scan (A SCAN) ==============================
// One-time diagnostic: the four accel wires are plugged onto pins
// 33/34/35/36 in an unknown order, and this finds which permutation
// makes a LIS3DH answer WHO_AM_I=0x33. Unlike the streaming path, the
// pin roles here are runtime values (not the PIN_* constants), so it
// uses its own plain digitalWrite/digitalRead bit-bang with generous
// 5 us phases - correctness over speed, this runs while the user is at
// the bench wiring, not in the realtime loop. When done it restores the
// normal bus/CS pin state and re-probes, so a correctly wired sensor is
// usable immediately without a reboot.
static const uint8_t SCAN_PINS[4] = {33, 34, 35, 36};

static inline void scanDelay() {
  delayMicroseconds(5);
}

static uint8_t scanSpiTransfer(uint8_t sck, uint8_t mosi, uint8_t miso,
                               uint8_t data) {
  uint8_t rx = 0;
  for (int i = 7; i >= 0; --i) {
    digitalWrite(sck, HIGH);          // CPOL=1 idle high
    scanDelay();
    digitalWrite(mosi, (data >> i) & 0x01);
    scanDelay();
    digitalWrite(sck, LOW);           // falling edge
    scanDelay();
    rx <<= 1;
    if (digitalRead(miso)) rx |= 1;   // sample MISO
    scanDelay();
  }
  digitalWrite(sck, HIGH);            // return clock to idle high
  scanDelay();
  return rx;
}

static uint8_t scanReadReg(uint8_t cs, uint8_t sck, uint8_t mosi,
                           uint8_t miso, uint8_t reg) {
  digitalWrite(cs, LOW);
  scanDelay();
  scanSpiTransfer(sck, mosi, miso, 0x80 | reg);   // read single register
  uint8_t v = scanSpiTransfer(sck, mosi, miso, 0x00);
  digitalWrite(cs, HIGH);
  scanDelay();
  return v;
}
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

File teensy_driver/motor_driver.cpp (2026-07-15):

#include "motor_driver.h"

// Motor channels: 0-9 finger motors, 10/11 ERM/LRA test channels that
// double as spares. Pin 12 is deliberately NOT claimed - it is reserved
// for SPI - and pin 13 carries the onboard LED.
static const uint8_t PWM_PINS[] = {0,1,2,3,4,5,6,7,8,9,10,11};
static const uint8_t NUM_PWM = sizeof(PWM_PINS) / sizeof(PWM_PINS[0]);
// Boot-time PWM frequency for every motor pin: the LRA's measured
// resonant frequency (see experiments/lra_frequency_sweep, 2026-07-15).
// ERMs are insensitive to drive frequency, so sharing this value is safe.
static const uint32_t DEFAULT_PWM_FREQ = 224;

// 'F' command frequency limits, clamped to a range that makes sense for
// vibration motors. Every motor pin is addressable, same as P/S, so a
// motor moved onto a spare channel stays fully controllable without
// re-flashing.
static const uint32_t FREQ_MIN = 50;
static const uint32_t FREQ_MAX = 20000;

// Last duty written to each pin, so a frequency change can re-apply it
// (changing the timer period invalidates the old duty registers).
static uint8_t currentAmp[NUM_PWM];

// Motor pulse task state
struct MotorTask {
  bool active;
  uint8_t amp;
  uint16_t remaining;   // pulses left
  uint32_t on_ms;
  uint32_t off_ms;

  bool state_on;
  uint32_t next_ts;
};

static MotorTask motors[NUM_PWM];

// Single write path for motor PWM so currentAmp always matches the hardware
static void writeMotor(uint8_t idx, uint8_t amp) {
  analogWrite(PWM_PINS[idx], amp);
  currentAmp[idx] = amp;
}

// On Teensy 4.1, pins on the same FlexPWM submodule always share one PWM
// frequency. Within motor pins 0-11 the coupled pairs are: 2&3 (FlexPWM4.2),
// 6&9 (FlexPWM2.2), 7&8 (FlexPWM1.3). Pins 10 and 11 sit on individual
// QuadTimer channels and are fully independent.
static int8_t sharedPartner(uint8_t idx) {
  switch (idx) {
    case 2: return 3;
    case 3: return 2;
    case 6: return 9;
    case 9: return 6;
    case 7: return 8;
    case 8: return 7;
    default: return -1;
  }
}

// Change one pin's PWM frequency, then re-apply the current duty to that
// pin and to any pin sharing its timer submodule.
static void setPinFrequency(uint8_t idx, uint32_t freq) {
#if defined(TEENSYDUINO)
  analogWriteFrequency(PWM_PINS[idx], (float)freq);
#endif
  writeMotor(idx, currentAmp[idx]);
  int8_t partner = sharedPartner(idx);
  if (partner >= 0) writeMotor((uint8_t)partner, currentAmp[partner]);
}

// Init all motor output pins
static void initPins() {
  for (uint8_t i = 0; i < NUM_PWM; i++) {
    pinMode(PWM_PINS[i], OUTPUT);
    digitalWrite(PWM_PINS[i], LOW);
    writeMotor(i, 0);
  }
}

// Set default PWM frequency on Teensy
static void initDefaultFrequencies() {
#if defined(TEENSYDUINO)
  for (uint8_t i = 0; i < NUM_PWM; i++) {
    analogWriteFrequency(PWM_PINS[i], (float)DEFAULT_PWM_FREQ);
  }
#endif
}

// Start one pulse task for one motor
static void startTask(uint8_t idx, uint16_t count, uint8_t amp, uint32_t on_ms, uint32_t off_ms) {
  if (idx >= NUM_PWM) return;

  MotorTask &m = motors[idx];

  m.active = true;
  m.amp = amp;
  m.remaining = count;
  m.on_ms = on_ms;
  m.off_ms = off_ms;

  m.state_on = true;
  m.next_ts = millis() + on_ms;

  writeMotor(idx, amp);
}

// Public init
void motorInit() {
  initPins();
  initDefaultFrequencies();
  stopAll();
}

// Stop all motors immediately
void stopAll() {
  for (uint8_t i = 0; i < NUM_PWM; i++) {
    motors[i].active = false;
    writeMotor(i, 0);
  }
}

// Non-blocking motor scheduler
void updateMotors() {
  uint32_t now = millis();

  for (uint8_t i = 0; i < NUM_PWM; i++) {
    MotorTask &m = motors[i];

    if (!m.active) continue;
    if (now < m.next_ts) continue;

    if (m.state_on) {
      // Turn motor off
      writeMotor(i, 0);
      m.state_on = false;
      m.next_ts = now + m.off_ms;
      m.remaining--;

      if (m.remaining == 0) {
        m.active = false;
      }
    } else {
      // Turn motor on again
      writeMotor(i, m.amp);
      m.state_on = true;
      m.next_ts = now + m.on_ms;
    }
  }
}

// Parse command: P idx count amp on_ms off_ms
void handlePulse(char* p) {
  long idx, count, amp, on_ms, off_ms;

  if (sscanf(p, "%ld %ld %ld %ld %ld",
             &idx, &count, &amp, &on_ms, &off_ms) == 5) {

    if (idx >= 0 && idx < NUM_PWM &&
        count > 0 &&
        amp >= 0 && amp <= 255) {

      startTask((uint8_t)idx,
                (uint16_t)count,
                (uint8_t)amp,
                (uint32_t)on_ms,
                (uint32_t)off_ms);
    }
  }
}

// Parse command: S mask amp
void handleImmediate(char* p) {
  long mask, amp;
  if (sscanf(p, "%ld %ld", &mask, &amp) == 2) {
    for (uint8_t i = 0; i < NUM_PWM; i++) {
      if (mask & (1 << i)) {
        writeMotor(i, amp);
      } else {
        writeMotor(i, 0);
      }
      motors[i].active = false;
    }
  }
}

// Parse command: F idx freq   (idx 0-11, or -1 for all motor pins)
void handleFrequency(char* p) {
  long idx, freq;

  if (sscanf(p, "%ld %ld", &idx, &freq) != 2) return;
  if (freq < (long)FREQ_MIN || freq > (long)FREQ_MAX) return;

  if (idx == -1) {
    for (uint8_t i = 0; i < NUM_PWM; i++) {
      setPinFrequency(i, (uint32_t)freq);
    }
  } else if (idx >= 0 && idx < NUM_PWM) {
    setPinFrequency((uint8_t)idx, (uint32_t)freq);
  }
}

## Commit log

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2026-07-03 Reduce serial command latency in Teensy firmware
    Dispatch already-arrived serial commands before running the
    motor/LED/accel subsystem updates, so a command isn't stuck waiting
    behind them. Switch LED output from FastLED (bit-banged, disables
    interrupts for the whole strip refresh) to WS2812Serial (hardware
    UART + DMA, non-blocking), moving the strip data pins from 22/23 to
    24/29 to match WS2812Serial's supported pins on Teensy 4.1.
    [LED_array.cpp, teensy_driver.ino]
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2026-07-04 Fix unstaged content edits from previous reorg commit, sync renamed profile/script
    The previous commit only captured file moves (git mv), not the import-path
    and doc edits made afterward, so it shipped stale references (fingeraccuracy.*,
    old data/ paths, old serial_utils/led_controller/controller imports, old
    main.py name). This commit lands those edits for real, and also picks up two
    renames that happened on disk outside git during that work: the calibration
    profile data/keyboard-profile/20260603A/ -> 20260603/, and
    test-script/demo_async.py -> demo_send_motor_command_async.py.
    [controller.py, led_controller.py]
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2026-07-15 Firmware v2.6.0: shrink motor set to pins 0-11, reserve pin 12 for SPI
    Motor driver (motor_driver.cpp, teensy_driver.ino):
    - Reduce PWM_PINS from 16 pins (0-15) to 12 (0-11): 0-9 finger motors,
    10/11 ERM/LRA test channels that now double as the spare channels.
    NUM_PWM is derived from the array length, so future pin-set changes
    touch one line only.
    - Pins 12-15 are no longer initialized or addressable: pin 12 is
    reserved for SPI (SPI0 MISO), pin 13 carries the onboard orange LED
    (and SPI0 SCK), 14/15 are simply unclaimed. They stay in the chip's
    default high-impedance input state.
    - The F command range and the S command mask therefore cover bits 0-11;
    mask bits 12-15 are ignored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
    [motor_driver.cpp, teensy_driver.ino]
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2026-07-15 Firmware v2.7.0 + LRA calibration: 224 Hz resonance, amp=64 default intensity
    Calibration experiments (new: experiments/lra_frequency_sweep/):
    - lra_frequency_sweep.py: two-pass frequency sweep (coarse 100-350 Hz
    in 5 Hz steps, then fine 1 Hz steps around the peak) at amp=128,
    measuring per-step RMS acceleration against a re-measured baseline.
    Result: mounted resonance f0 = 224 Hz (Blu-Tack desk mount), ~2.8x
    more vibration than the old 300 Hz default at the same drive.
    - lra_amplitude_sweep.py: amplitude sweep 4-128 at the 224 Hz
    resonance, converted to absolute units (LIS3DH HR +/-2 g, 1 count =
    1 mg). Result: amp=64 lands at 0.49 m/s^2 RMS, the centre of the
    0.4-0.6 m/s^2 pe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
    [amp_sweep_20260715_153925.csv, sweep_20260715_152236.csv]
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2026-07-17 Per-event review & finger correction, participant CSV export, confusion-matrix polish
    Quiz Detail / event review (new app/gui/event_review_window.py):
    - Double-clicking an event row now opens a playback window: the
    recording around that keypress (±5 s, mapped through the trial's sync
    anchor), frame-precision slider, play/pause at 0.5/0.75/1/1.25×, and
    a jump-to-keypress button landing on the exact keypress frame.
    - The detected Actual Finger can be corrected from the physical finger
    list (L5..L1, R1..R5, or Unresolved) - changing a correct finger to a
    wrong one requires picking which finger was actually pressed.
    - A correction writes ONLY actual_finger and re-judges finger_correc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
    [P02_events.csv, P02_trials.csv]
2026-07-18 Participant Analysis window (launcher section 7), pandas computation layer, export polish; README updated
    Participant Analysis (new app/gui/participant_analysis_window.py):
    - Cross-trial single-participant view over the 27-trial session, nine
    tabs, each chart with an auto-generated numeric caption:
    Overview / Learning (whole-session trend + within-cell trial 1->3
    order) / Difficulty / Trade-off / Errors / Confusion / Fingers /
    Timing / Quality.
    - Speed-accuracy trade-off: one point per trial, per-condition centroid
    diamonds with two-way SD error bars, no regression or connecting
    lines (9 trials/condition can't support a fit); trials without a
    valid correct-key RT are excluded a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
    [P02_confusion_long.csv, P02_error_breakdown.csv, P02_tradeoff_centroids.csv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]
2026-07-19 Carry-over review workflow replaces anticipation/false-start labels
    Pilot data (P02) showed the 'anticipation'/'false starts' framing was
    wrong: unmatched raw presses are near-simultaneous double-hits or
    inter-trial strays from the previous response, not early reactions to
    the next cue, and one implausibly fast matched response (T02 event 6,
    RT 85 ms) was the tail of the previous trial's presses being scored.
    - QuizResult.validity ("valid"/"invalid_carryover"), human-set only via
    right-click in the quiz detail window; invalid events are excluded
    from every summarize() statistic (RT and accuracy alike)
    - summarize(): anticipation -> suspected_carryover (matched RT < 100 ms,
    needs manua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
    [P02_events.csv, P02_trials.csv]
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2026-07-22 Motor->ACC delay experiment: launcher integration, suspended-rig protocol, CUSUM onset metric; firmware v2.9.0
    - validation_experiments/motor_acc_delay_experiment/: merged successor of the
    old LRA/ERM script pair - actuator type, motor port, ACC sensor and stillness
    limit are parameters; single serial connection (the old scripts double-opened
    the port); full README write-up
    - Measurement protocol: rig suspended freely in the air (desk mounting damps
    the calibrated cue below detectability), any starting orientation, automatic
    per-trial stillness gate with noise-floor hints and adjustable limit
    - Detection rework: per-axis deviation against per-trial baselines (the old
    | |a|-baseli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
    [delay_samples_1784732349.csv, delay_samples_1784732666.csv, delay_trials_1776436899.csv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]
2026-07-22 Restructure repository: python-code -> main, consolidate all archives under archived/
    - Rename python-code/ to main/ and archived_version/ to archived/ (975 files,
    history preserved via git mv; all code uses relative paths, so launcher,
    validation experiments and data resolution work unchanged)
    - Consolidate archives: experiments/attachment_verification_experiement moved
    to archived/ (completed one-off study, Blu Tack outcome locked in the
    report), python-code/archive merged in as archived/python-prototypes
    (FingerAccuracy v2-v4 prototypes, one-off utilities, old bug reports);
    the emptied experiments/ directory is removed
    - archived/README.md documents every archived folder in th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
    [1799551287.csv, Battery-Cover.STL, P02_confusion_long.csv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]
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2026-07-24 Wiring Guide window + firmware A SCAN accelerometer wiring probe; fw v2.10.0
    Firmware: new "A SCAN" command brute-forces the accelerometer wiring on
    pins 33/34/35/36 - tries all 24 SCK/MOSI/MISO/CS role permutations, reads
    WHO_AM_I 3x each, reports the permutation that stably answers 0x33, then
    restores the normal bus/CS state and re-probes so a correctly wired
    sensor is usable immediately. Read-only diagnostic; runs its own slow
    runtime-pin bit-bang, never touches the streaming pin mapping.
    Host: new tabbed Wiring Guide (launcher section 1) alongside a labelled
    Teensy 4.1 pinout - Power rails / Pin assignments / Accelerometer scan
    tabs. The scan tab drives A SCAN on a worker thread and int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
    [accel_driver.cpp, teensy_driver.ino]
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2026-07-29 Add Actuator Spectrogram experiment; remove ERM sweeps; Motor Bench + live ACC view
    - validation: new Actuator Spectrogram (2-D drive-frequency x amp intensity
    map for ERM/LRA). Adjustable amp/frequency ranges seeded from the type,
    scan precision, per-cell vibrate time, and per-cell value annotation
    (RMS or normalized) that re-renders and saves the run's own PNG live.
    Saves grid (NPZ), heatmap (PNG), CSV + meta.
    - validation: remove ERM PWM-Frequency Sweep and ERM Amplitude Sweep
    (code and data), including from the launcher.
    - Haptic Motor Bench: add "Open Accelerometer Live View" that shares the
    single serial port, so driving and the live plot run at the same time.
    - launcher: r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
    [erm_pwm_sweep_1784902631.csv, erm_pwm_sweep_1784904808.csv, erm_sweep_1784901378.csv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]
2026-07-30 Validation experiments: onset/settling metrics, per-metric cue targets, GUI fixes
    Motor -> ACC Delay
    - Adjustable vibration duration (0.5-10 s, default 2 s): the motor runs
    for the whole window and every raw X/Y/Z sample of it is stored.
    - Two SEPARATE times per trial - vibration onset latency (CUSUM
    change-point, with a persistence gate so a knock is never dated as the
    onset) and settling time (centred moving-RMS envelope entering and
    holding a steady band). Both settling forms are saved
    (settling_time_from_onset_ms, stable_latency_from_command_ms) with the
    three instants they come from, and an explicit per-trial status
    (ok / no_onset / not_settled / insufficient_data). A tria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
    [amp_sweep_1784126365.csv, amp_sweep_1784728858.csv, amp_sweep_1784728912.csv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]
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2026-07-30 Add Adhesion Vibration Comparison validation experiment (LRA) + multi-run analysis
    Experiment (one adhesive per run, LRA-only): drive is fixed to
    config.json haptic.lra - read even when using=erm - and shown read-only,
    so every run is driven identically. Per trial: quiet baseline,
    timestamped motor-on, the whole drive window recorded losslessly.
    Onset/rise/settling reuse the Motor -> ACC Delay detector; the steady
    state adds vector RMS, absolute + robust p99 peaks, peak-to-peak, the
    spectrum, the amplitude at the drive frequency, harmonics and THD. A
    not_settled trial keeps an empty settling time and is excluded from the
    steady-state statistics.
    Comparison: any number of runs per method, at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
    [adhesion_blu_tack_1785428556.csv, adhesion_comparison_1785429699.csv, adhesion_comparison_1785446616.csv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]
2026-07-31 Add Condition x Finger RM-ANOVA and finger-benefit analyses; complete Group Analysis export
    Group Analysis gains the finger-specific model the method chapter
    specifies, plus three follow-up analyses and a complete export.
    RM-ANOVA (app/group_analysis.py, new tab):
    - two-way within-participant ANOVA, Condition (B/C) x Finger ID (1-5),
    fitted on the per_finger_metrics cells via pingouin: F, df, partial
    eta squared, Mauchly's W and Greenhouse-Geisser per effect
    - Condition has two levels, so it is never GG-corrected; GG applies to
    the Finger main effect and the interaction only
    - finger accuracy stays descriptive (mean/SD/95% CI) with recomputed
    ceiling diagnostics; 23 of 70 cells sit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
    [_manifest.csv, condition_difficulty_group_summary.csv, condition_difficulty_participant_cells.csv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]
2026-07-31 Refresh group analysis export with the fitted Condition x Finger ANOVA
    Re-run of Export figures + data for P01-P07 (189 trials, 5670 events,
    5669 valid) with pingouin available, so the repeated-measures ANOVA is
    now fitted rather than skipped.
    Adds rm_anova_effects.csv, carrying both models (correct-complete-action
    RT and all-responded RT) with SS, MS, F, df, partial eta squared,
    Mauchly's W, the Greenhouse-Geisser epsilon and corrected p, and which
    p each effect reports.
    Results on the primary RT model, N = 7: Condition F(1,6) = 26.47,
    p = .002, partial eta squared = .82 (C faster by 242 ms); Finger ID
    F(4,24) = 8.94, p < .001; Condition x Finger F(4,24) = 0.99, p = .43.
    The null interact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
    [_manifest.csv, finger_benefit_summary.csv, rm_anova_effects.csv]
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2026-08-03 Refine group analysis methods and difficulty labels
    - Add within-cell repetition and nine-trial difficulty progression analyses for RT and key accuracy.
    - Preserve Condition A in overview and trade-off baselines while keeping within-cell progression comparisons focused on B/C.
    - Separate automatic threshold-sensitivity estimates from the final corrected FA reference.
    - Use two-factor repeated-measures ANOVA with Greenhouse-Geisser-corrected inference and expanded result exports.
    - Standardize difficulty terminology as alpha, beta, and gamma throughout analysis code and experiment interfaces.
    - Extend regression tests and regenerate the complete group-analysis output set.
    [_manifest.csv, condition_difficulty_group_summary.csv, condition_difficulty_participant_cells.csv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]
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2026-08-04 Add data for P09
    All 27 trials: meta, per-event results, raw MIDI/notes/sync and the
    per-frame hand landmarks, plus the participant's trial structure and
    exported trial/event CSVs. Videos stay untracked as usual.
    Finger verdicts include the manual review pass. Whether an event counts
    as hand-corrected is derived from these files at read time, so it
    already follows the tie fix in the previous commit - the stored results
    needed no re-analysis for it.
    [P09_events.csv, P09_trials.csv]
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2026-08-05 Add data for P10
    per-frame hand landmarks, plus the trial structure and the exported
    trial/event CSVs. Videos stay untracked as usual.
    Finger verdicts include the manual review pass. Twelve of the trials
    were corrected after QuizResult grew finger_corrected, so their
    results.json carries that field while the earlier participants' do not -
    the field defaults to False on load, and a correction made before it
    existed is still recognised by inference.
    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
    [P10_events.csv, P10_trials.csv]
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2026-08-05 Re-export P01-P09 under the corrected manual-correction flag
    Group Analysis reads these CSVs rather than results.json, so the fix to
    finger_manually_corrected only reaches the group numbers once the export
    runs again. The 277 changed cells are all manually_corrected and its
    per-trial count: the tie false positives dropped, the corrections the
    old inference missed appeared. Every verdict column - actual_finger,
    finger_correct, note_correct, validity - was already in sync with the
    reviewed data and is unchanged.
    Also ignores main/normalisation/, a local folder of data-maintenance
    scripts, and restores the newline the ignore file had lost.
    [P01_events.csv, P01_trials.csv, P02_events.csv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]
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2026-08-05 Share the participant-level analysis between both windows
    Everything in group_analysis that reduced one participant's rows to that
    participant's own numbers now lives in participant_analysis, which the
    group module re-exports unchanged. The single-participant window can
    therefore show the same tables without importing a group module, and
    group_analysis keeps only what needs more than one participant: the
    group centre and its interval, the paired contrasts, the RM-ANOVA.
    That fixes a real disagreement. The participant window fed raw event
    rows to the event-level tabs, so manually confirmed carry-over presses
    were counted there while the trial-level statistics printed beside them
    had already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
    [P01__manifest.csv, P01_confusion_long.csv, P01_difficulty_cell_metrics.csv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]
2026-08-06 Add the ERM sweep and motor-delay validation runs
    Four runs on the ERM actuator, all on firmware v2.10.0 with the
    accelerometer sampling at 1 kHz and the motor free-hanging.
    Actuator sweeps (amp 0-255, medium precision):
    - 1785947933 sweeps to 1000 Hz, peak vector RMS 10.19 m/s^2 at 450 Hz
    - 1786025767 sweeps to 5000 Hz, peak vector RMS 10.42 m/s^2 at 500 Hz
    The wider sweep finds nothing above the first band, so the ERM output is
    flat past roughly 500 Hz and the narrow sweep is enough from here on.
    Motor-to-acceleration delay, 10 trials each at 1 kHz PWM:
    - 1786035628 at amp 50 (the config default) fails to settle in every
    trial: 6 with no detected onset, 4 that never reach a steady enve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
    [delay_samples_1786035628.csv, delay_samples_1786035719.csv, delay_trials_1786035628.csv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]
2026-08-06 Retune the ERM sweep and cue level from the measured runs
    What the runs in the previous commit changed my mind about.
    Spectrogram:
    - The ERM default sweep is now 50-5000 Hz, not 0-1000 Hz. The 5 kHz run
    showed nothing above the first band, so the wide range is what proves
    that rather than an assumption about where to stop looking.
    - Motor-off rest is now per actuator: ERM 2.00 s, LRA 0.15 s. At the old
    0.15 s the rotor was still spinning when the next cell started, so a
    cell measured its predecessor as much as itself. REST_S stays as an
    alias for the LRA value so existing callers keep working.
    - Selecting an actuator type no longer moves the motor port. Port and
    type are indepen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
    [haptic_config.py]
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2026-08-13 Regenerate group figures with P13 included
    Group analysis rerun covering P01-P13: the 86 existing outputs are
    refreshed and 21 new ones appear, mostly the Condition A free-fingering
    strategy set (finger and hand usage, motor-demand proxies, occurrence and
    within-difficulty summaries) plus the log-scaled key-error progression
    plot.
    [_manifest.csv, condition_a_finger_usage.csv, condition_a_finger_usage_group_summary.csv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]
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2026-08-14 Group finger-confusion analysis, progress dialogs, and window handling
    Five threads from one session on the analysis tooling; they led to each
    other, so they land together.
    A group-level finger confusion analysis. finger_confusion() pools every
    participant and trial into one target x detected table and
    confusion_grid()/confusion_totals() turn it into the 10x10 grids a new
    Finger Confusion tab draws - all participants and all cued trials in one
    matrix, then the same split by condition. Each cell carries two counts:
    how many events landed there, and how many of those still scored
    finger-correct. They answer different questions and the difference is
    easy to misread, because the detected finger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
    [P13__manifest.csv, _manifest.csv, confusion_group_long.csv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]
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2026-08-19 Create the benchmark's room itself, pace it like a person, and plot it
    Rooms are no longer the operator's job. Both modes create and close their
    own temporary room; external mode prints its join code and waits on the
    relay's presence frame until a real Student Client is in there, so early
    probes cannot be scored as transport loss. --room-id survives only as the
    escape hatch for a client already in a room. The membership is read back
    once both sockets are up, because a run whose endpoints sat in different
    rooms would just lose everything.
    Probe pacing becomes a choice: fixed, uniform, poisson (RFC 2330) or
    human, all with the same mean, seeded and recorded so a randomised run
    can be repeated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
    [samples.csv]
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2026-08-27 Add Computational Model Analysis: effector-selection model and out-of-sample prediction
    Fits every keypress as a choice among the ten fingers - a habitual prior
    and a reachability term against the evidence the cue supplies - so the
    A/B/C pattern is accounted for by one set of parameters rather than
    described three times.
    The cue is modelled as saying two separable things, which hand and which
    digit, and that is where the result is: the haptic cue strengthens the
    hand channel and leaves the digit channel essentially unchanged (tying
    the two conditions on the hand channel costs 43.4 log-likelihood against
    2.2 on the digit channel). The wrong-hand and homologous error classes
    appear nowhere in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
    [_manifest.csv, model_channel_test.csv, model_coefficients.csv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]
2026-08-27 Make the prediction prospective, fix the paired-contrast scope, drop the uniqueness claim
    Four corrections, two of them substantive.
    The reach term read the key that was actually pressed. That key is part
    of the response, so a model reading it can describe an event but cannot
    be said to predict it - the participant-level isolation was sound, the
    feature set was not. ModelSpec.key_source now selects the cued key by
    default; conditioning on the pressed key stays available as a
    descriptive sensitivity fit. The two differ on 120 of 16,195 events
    (0.74%): hand evidence moves 5.170 -> 5.165 under B and 8.856 -> 8.816
    under C, the prior weights do not move, and the risk-enrichment counts
    are uncha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
    [_manifest.csv, model_channel_test.csv, model_coefficients.csv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]
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2026-08-28 Let the seed choose between the best five melodies, not only the best
    Different seeds kept returning the same tune. The cause was the last
    line of the search: it ranked the candidate pool and took the argmax.
    A 40-candidate pool holds about 39 DIFFERENT melodies - the search
    itself was never short of variety - and keeping one of them meant
    whichever shape was both easy to sample and high-scoring won again and
    again. Measured across 300 seeds, one melody came up in 9.3% of runs and
    the top five in 20%, so asking for a new seed and getting the tune you
    already had was ordinary rather than unlucky.
    Every candidate in that pool has already passed validation,
    max_difficulty and min_musicality.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
    [melody_seed42.csv]
2026-08-28 Score a performance by alignment, accept a press played in the gap, and give a probe the pitch without the time
    Three faults found in Tester 1's session, in the order they mattered.
    A PRESS PLAYED IN THE GAP WAS DISCARDED
    The quiz loop only accepts a response from the cue onwards, and there is
    a 0.4 s gap after every note before the next cue. Holding a training cue
    for the whole beat - added two commits ago - made that trivially easy to
    hit: the natural moment to play the next note is the instant the buzz
    stops, which is exactly one gap before the cue. The participant pressed,
    nothing happened, and they had to press again. 26 presses were lost this
    way in one session. The response window no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
    [melody_seed415411.csv, melody_seed42.csv, rhythm_events.csv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]
2026-08-28 Stop tracking the rhythm analysis output; it is regenerated from tracked data
    The export that got committed alongside the last change was already
    stale: it was produced before the timing measure moved from absolute
    onset error to inter-onset-interval error, so its summary reports a
    column the analysis no longer has, and probe_absolute_onset_error.png is
    a filename nothing will overwrite again.
    Everything it is made from is tracked - the per-trial quizzes under
    data/quiz/rhythm-* and each participant's TrialStructure.json - so the
    whole folder is one Export away at any time.
    [rhythm_events.csv, rhythm_participants.csv, rhythm_trials.csv]
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2026-09-01 Group Analysis: unify on bootstrap CIs, add participant-line toggle, refine axes & exports
    Statistics — all Group Analysis 95% CIs are now a participant percentile
    bootstrap (10,000 resamples, seed 20260901, 2.5/97.5 percentiles), replacing
    the t-interval:
    - New ga.bootstrap_ci() is the single chokepoint; group_center() calls it, so
    every descriptive band/error bar switches over (Condition x Difficulty,
    Overview, within-cell repetition, session position, RM-ANOVA cell means and
    interaction diffs, trade-off, errors, finger-benefit descriptive, quality).
    - Also converted off the t-interval: the Contrasts figure bar and
    condition_inference's paired-difference CI, plus condition_a_stra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
    [_manifest.csv, condition_a_finger_usage_group_summary.csv, condition_a_motor_demand_group_summary.csv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]
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
